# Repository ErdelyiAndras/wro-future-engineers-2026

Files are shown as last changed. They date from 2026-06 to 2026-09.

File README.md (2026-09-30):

# WRO Future Engineers 2026

## Introduction

We're team Bits from Hungary, competing in the WRO Future Engineers category. This engineering documentation covers all major aspects of the robot's development: mobility management, power and sensor systems, obstacle detection, avoidance and construction design.

### Team members:

 - András Erdélyi
 - Balázs Erdélyi

### Coach:

 - Norbert Boros

## Abstract

Our solution is an autonomous robot built around a Raspberry Pi 5 programmed in Python and C++, responsible for the main challenge logic and vision processing, and an Arduino Nano, responsible for low-level tasks such as motor and servo control. We use a 360° RPLIDAR A2M8 combined with the gyroscope of a BNO055 IMU to track the robot's position and heading. Traffic signs are detected with a USB camera. Steering uses a HS-485HB servo with positive Ackermann geometry. Driving is powered by one N20E-12-500 DC motor and a DRV8871 H-bridge, through a rear-axle differential with a custom 3D-printed housing. The compact dual-plate chassis is powered by a custom 3S 18650 battery pack with a BMS and buck converters.

## Table of Contents

- ### Videos

    - [**Open Challenge**](https://www.youtube.com/watch?v=D1SUvafeCVA)
    - [**Obstacle Challenge**](https://youtu.be/72qxD-1WuEM)

- ### Hardware
    -  [**Assembly Overview**](docs/hardware/assembly-overview.md)
    -  [**Drive System**](docs/hardware/drive-system.md)
    -  [**Processing Units**](docs/hardware/processing-units.md)
    -  [**Sensors**](docs/hardware/sensors.md)
    -  [**Power and Electronics**](docs/hardware/power-and-electronics.md)
    -  [**Circuit Design**](docs/hardware/circuit-design.md)
    -  [**Cost of the Robot**](docs/hardware/cost-of-the-robot.md)
    -  [**3D Print**](docs/hardware/3d-print.md)
    -  [**Assembly Guide**](docs/hardware/assembly-guide.md)

- ### Software
    -  [**Architecture Overview**](docs/software/architecture.md)
    -  [**Components**](src/rpi/components/README.md)
    -  [**Control / Blackboard**](src/rpi/control/README.md)
    -  [**Processors & Planning Algorithm**](src/rpi/processors/README.md)
    -  [**Recording & Replay**](src/rpi/recording/README.md)
    -  [**Visualizers**](src/rpi/visu/README.md)
    -  [**Arduino Firmware**](src/arduino/README.md)
    -  [**Calibration**](calibration/README.md)
    -  [**Previous Approaches**](docs/software/previous-approaches.md)
    -  [**Developer & Setup Guide**](docs/software/setup-guide.md)

## Special Thanks

We'd like to thank Széchenyi István University, Facenter Kft., and Filasin for supplying us all the equipment that made our preparation possible.

<table>
<tr>
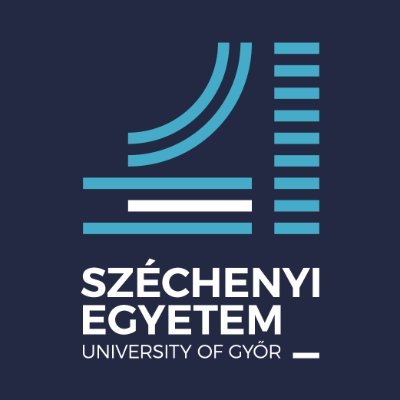
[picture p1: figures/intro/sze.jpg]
<td valign="top" width="240"></td>
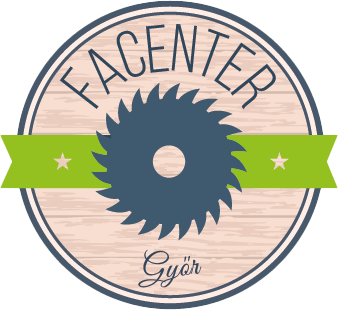
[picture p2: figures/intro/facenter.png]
<td valign="top" width="240"></td>
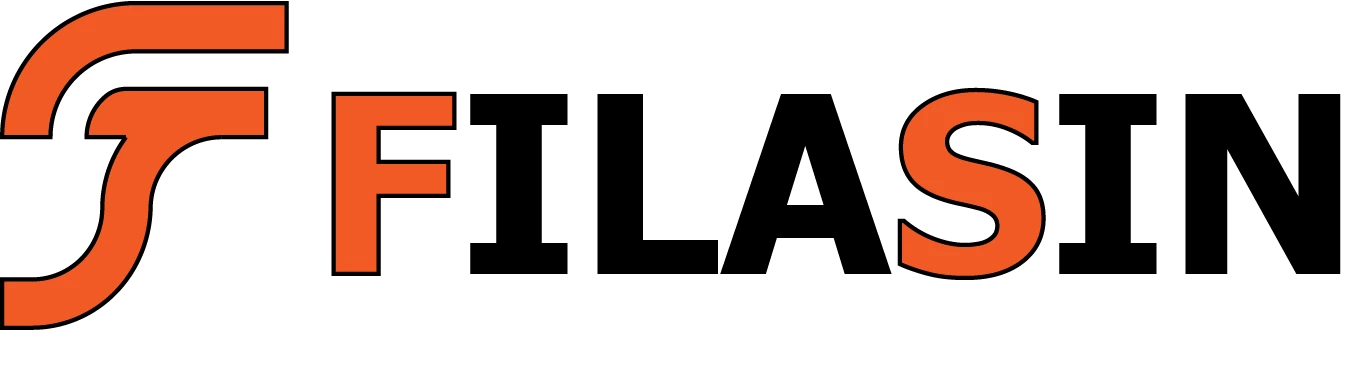
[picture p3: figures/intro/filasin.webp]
<td valign="center" width="240"></td>
</tr>
</table>

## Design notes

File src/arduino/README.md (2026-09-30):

# Arduino firmware

The Arduino Nano runs the **real-time motion layer**. It owns the BNO055 IMU and the wheel
encoder, receives body-frame targets from the Raspberry Pi over a framed serial link, and
drives the motor and steering to reach them — all in a tight loop (≥ 50 Hz). The Pi decides
*where* to go; this firmware decides *how* to get there. See the
[architecture overview](../../docs/software/architecture.md) for the split.

Build and flash with the repo `Makefile` (`make flash`, FQBN
`arduino:avr:nano:cpu=atmega328`); see the
[developer guide](../../docs/software/setup-guide.md#flashing-the-arduino).

## Main loop — [`arduino.ino`](arduino.ino)

`setup()` initialises the encoder, IMU, motor, steering, and protocol callbacks. `loop()`
runs every iteration:

```
encoder.update();      // refresh speed
imuCtrl.update();      // refresh heading
protocol.update();     // parse any incoming frames -> onSetTarget / onStop
navigator.update();    // pursue the current target
motor.update();        // apply the motor command (with kickstart)
// every 20 ms: protocol.sendState(heading, speed, steering, delta_distance)
```

So the Pi receives a `STATE` frame at **50 Hz** (`STATE_REPORT_INTERVAL_MS = 20`). The
modules are cooperating singletons (`navigator`, `motor`, `encoder`, …) configured entirely
from [`Config.h`](Config.h).

## `Protocol` — framed UART — [`Protocol.cpp`](Protocol.cpp)

The binary framing layer. Frame format:

```
[0xAA] [MSG_ID] [LEN] [PAYLOAD × LEN] [CRC8]
```

CRC-8 (polynomial `0x07`) is computed over `MSG_ID + LEN + PAYLOAD`; on a bad start byte or
CRC the parser drops one byte and resyncs. Messages:

| ID | Dir | Name | Payload |
|---|---|---|---|
| `0x01` | Pi → Nano | `SET_TARGET` | `forward_mm, lateral_mm, speed` (3× f32) |
| `0x02` | Nano → Pi | `STATE` | `heading_rad, speed, steering_rad, distance_mm` (4× f32) |
| `0x03` | Pi → Nano | `STOP` | empty |

`STATE.distance_mm` is the encoder distance **since the last report** (the Pi's EKF predict
step). The Python half of this protocol is [`components/Arduino.py`](../rpi/components/README.md).

## `Navigator` — pursuit + heading PID — [`Navigator.cpp`](Navigator.cpp)

The motion controller. `setTarget(forward, lateral, speed)`:

- **rejects unreachable targets** — a point inside either minimum-turn-radius circle
  (`r = wheelbase / tan(MAX_STEER)`) can't be reached with Ackermann steering, so the state
  goes `IDLE`. (This is why the planner runs every target through `_make_reachable`.)
- resets its local body frame (`x = y = 0`, heading reference = current IMU heading) and
  starts `PURSUING`. A **negative speed means reverse** (the steering sign is flipped).

`doPursuing()` each tick: integrate encoder distance into the local `(x, y)` using the IMU
heading; compute the heading error to the target (switching to a **heading-hold** mode within
100 mm to avoid oscillation); run a **PID** on that error (filtered derivative, clamped
integral) to a clamped steering angle; and set a speed with an **acceleration ramp** over the
first 200 mm and a **deceleration ramp** over the last 500 mm. Arrival (within 10 mm) brakes
and idles.

Key constants (`Config.h`): `HEADING_KP/KI/KD = −2.5 / −0.7 / −0.155`,
`HEADING_HOLD_RADIUS = 100 mm`, `ARRIVAL = 10 mm`, `MIN_SPEED = 80`, `MAX_STEER = 0.4014 rad`.

> **No serial watchdog.** The firmware does not auto-stop if the Pi goes silent; a `STOP`
> frame (or the start button on the Pi) ends a run. Worth adding before competition.

## `Motor` — [`Motor.cpp`](Motor.cpp)

Drives the DC motor via two PWM channels (forward `D5`, reverse `D6`). Implements a
**kickstart**: starting from rest below the deadband, it briefly applies `MIN_SPEED` (80)
and decays toward the requested speed at `KICKSTART_DECAY = 200` units/s, overcoming static
friction without a jerk. `brake()` drives both channels high (active brake); `stop()` coasts.
`MOTOR_DIR = −1` accounts for the wiring polarity.

## `Steering` — [`Steering.cpp`](Steering.cpp)

Maps a steering angle (rad) to a servo pulse width, with **asymmetric** left/right ranges
because the servo's mechanical centre is off the electrical centre: centre `1050 µs`, full
left `1400 µs`, full right `500 µs`, max `±0.4014 rad`. These values live in
[`Config.h`](Config.h), measured from the servo pulse-width → wheel-angle mapping.

## `Encoder` — [`Encoder.cpp`](Encoder.cpp)

Quadrature decoding on interrupt pins `D2` / `D3`; `TICKS_PER_MM = 14.0`. Speed is sampled
every 50 ms; `distance` reported to the Pi is the delta since the last `STATE`.

## `IMU` — [`IMU.cpp`](IMU.cpp)

The BNO055 over I²C in **`OPERATION_MODE_IMUPLUS`** — gyro + accelerometer fusion, **no
magnetometer** (a magnetometer is unreliable near motors and metal). Heading is therefore
**relative**: it is zeroed at boot, so `yaw = 0` points wherever the robot happened to face
at power-on. Recovering "parallel to the wall" from that arbitrary zero is exactly the job of
the principal angle `theta` on the Pi side (see the
[processors chapter](../rpi/processors/README.md)).

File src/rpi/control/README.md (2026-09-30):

# Control — the blackboard

`control/` holds the **shared state** of the Raspberry Pi software: the thread-safe
"blackboard" that sensor threads write and the planner reads, plus the small value types the
colour pipeline uses. It holds **no maps or grids** — only the scalars the reactive stack
reasons about. See the [architecture overview](../../../docs/software/architecture.md) for
the blackboard pattern.

Each accessor takes a lock for only as long as it takes to read or write a few numbers, so
threads running at different rates never block each other.

## `EgoInformation` — [`EgoInformation.py`](EgoInformation.py)

The robot's pose estimate `[x, y, heading]`, maintained by a small **Extended Kalman
Filter**. It is updated by [`ArduinoProcessor`](../processors/README.md) on every `STATE`
frame (50 Hz):

- **Predict** — `update_odometry(ds, steering)` propagates the state with Ackermann
  kinematics (straight-line when steering ≈ 0, arc otherwise) and advances the covariance
  `P` through the analytic Jacobian plus a process-noise term scaled by the distance
  travelled.
- **Correct** — `update_imu(heading)` folds the BNO055 heading in as a scalar measurement,
  correcting heading drift.

The planner consumes **`yaw`** (heading) and, for dead-reckoning lateral drift within a
straight, the **`position`** deltas. It does **not** use the absolute `(x, y)` as a world
position — there is no map to place it in. The noise constants (`_PROCESS_NOISE_V`,
`_PROCESS_NOISE_W`, `_MEAS_NOISE_IMU_HDG`) are measured empirically on the assembled robot.

> Historical note: the EKF also has a LiDAR `[x, y, heading]` correction path in earlier
> revisions; the current reactive pipeline does not wire one in. See
> [Previous approaches](../../../docs/software/previous-approaches.md).

## `TrackModel` — [`TrackModel.py`](TrackModel.py)

The track as the robot currently understands it — a lock-protected bag of scalars written by
two processors and read by the planner:

| Field | Meaning | Written by |
|---|---|---|
| `theta` | principal angle: grid orientation, mod 90°, absolute (gyro) frame | `PrincipalAngleDetector` |
| `theta_seeded`, `theta_from_gyro`, `theta_frozen` | seed status / detection freeze | detector + planner |
| `seg_k` | grid multiple of the **current** straight; latched per straight, bumped by `turn_sign` at each corner | planner |
| `turn_sign` | `+1` CW / `−1` CCW, latched at the first corner | planner |
| `corner_count` | corners completed (12 = 3 laps) | planner |
| `current_lane`, `target_offset` | the lane held vs the lane aimed at | planner |
| `target_heading` | corner target heading | planner |

The one derived quantity, `segment_heading(yaw) = wrap(theta + seg_k·90°)`, lives here
because both its inputs do. Latching `seg_k` per straight (rather than re-deriving it from
the live yaw each scan) is what makes the mid-straight 90° "grid flip" structurally
impossible — a story told in [Previous approaches](../../../docs/software/previous-approaches.md).

## Colour types

- [`ColorRange.py`](ColorRange.py) — an HSV colour as the **union of one or more
  `(lower, upper)` bands**, so a hue that straddles the 0/180 seam (red, or the magenta
  parking wall) is two bands instead of being clipped. `mask()` / `ratio()` test a patch
  against it. The three ranges (red, green, parking) are produced by the
  [obstacle-colour calibration](../../../calibration/README.md#obstacle-colours) and pasted
  into `main_obstacle.py`.
- [`ObstacleColor.py`](ObstacleColor.py) — the `RED` / `GREEN` enum the pillar reader
  returns.

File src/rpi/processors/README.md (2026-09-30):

# Processors & the planning algorithm

Processors are the algorithms. Each subscribes to a component [`Event`](../utils/Event.py),
and inherits from [`Processor`](Processor.py) — a thin base whose `__call__` forwards to
`_process(...)` (and can be paused). This chapter covers the perception processors and then
the heart of the robot: the **reactive segment planner** and its state machine.

For how these wire into the rest of the system, see the
[architecture overview](../../../docs/software/architecture.md). For the ideas we tried
first (occupancy grid, SLAM, follow-the-gap), see
[Previous approaches](../../../docs/software/previous-approaches.md).

## Perception processors

- **[`ArduinoProcessor`](ArduinoProcessor.py)** — subscribes to `Arduino.on_state`. On each
  `STATE` frame it feeds `EgoInformation`: an odometry predict step (if the robot moved ≥
  0.5 mm) and an IMU heading correction. This is the only writer of the EKF pose.
- **[`CameraProcessor`](CameraProcessor.py)** — the **stateless, body-frame pillar-colour
  reader**. It keeps the latest camera frame and, on demand, answers
  `color_at(forward, lateral)`: project a body-frame point into the image through the camera
  intrinsics/extrinsics, sample a 20 px HSV patch, and classify it against the red/green
  [`ColorRange`s](../control/README.md). Because the extrinsics are body-relative, **no ego
  pose is involved** — the planner clusters a pillar in the *current* scan and hands its
  body point straight over. `parking_wall_ratio()` (whole-frame magenta) is used once at a
  parking-slot start. It also defines `CameraIntrinsics` / `CameraExtrinsics`.
- **[`PrincipalAngleDetector`](PrincipalAngleDetector.py)** — fits the track's principal
  angle `theta` each scan and publishes it to [`TrackModel`](../control/README.md); detailed
  below.

## The core idea

The planner is **deterministic, reactive, and sensor-only**. It *assumes* the WRO layout — a
rectangular loop of four straights joined by four 90° corners — and trades that assumption
for determinism. It keeps no occupancy grid, no world position, and no obstacle map. Two
principles carry the whole thing:

1. **Open-loop straights, closed-loop corners.** A straight is driven with **no lateral wall
   term**: the firmware holds heading toward an aim point placed down the segment, and
   lateral position is dead-reckoned from encoder + gyro. Every corner ends with a
   closed-loop **reset** (align to the new segment against the LiDAR rear wall). So lateral
   error can build up over at most *one* straight and is wiped at each corner — it never
   compounds across the three laps. This is also why the receding inner wall near a corner
   never corrupts anything: the straight simply does not look at the side walls.

2. **Gyro holds heading; LiDAR calibrates what "parallel" means.** The IMU zero is an
   arbitrary placement angle, so `yaw = 0` is not "parallel to the wall". The principal
   angle `theta` (grid orientation, mod 90°) is fit from the wall points; the current
   `segment_heading = theta + seg_k·90°` is what the straight is driven along. `theta` is
   yaw-invariant, so it stays valid through lane switches and corners.

Each scan the planner outputs just a body-frame aim point + speed; the firmware's
`Navigator` turns that into steering and motor commands (see the
[firmware chapter](../../arduino/README.md)).

## Principal angle `theta`

`PrincipalAngleDetector` estimates the grid orientation from **wall tangents**: between two
consecutive LiDAR returns on the same surface, the segment direction is a wall tangent. Both
corridor side walls and the perpendicular end wall lie on the same 90° grid, so every clean
tangent reinforces the same mod-90 angle. Tangents are accumulated as unit vectors on
`4·angle` (which handles the mod-90 wrap), length-weighted; the resultant length doubles as
a **fit-quality gate** — messy, mid-turn scans (low resultant) are skipped, clean straights
absorbed into a circular-mean EMA. The body-frame result is lifted into the absolute frame
with the gyro yaw, which is what makes `theta` yaw-invariant.

Because a corner start cannot produce a clean fit, if no LiDAR fit lands within
`_SEED_FALLBACK_SCANS` (12) scans the detector **seeds `theta` from the gyro** so the robot
can start moving; the EMA then refines it once a straight is in view. The detector is wired
**before** the planner on the LiDAR thread, so the planner reads a fresh `theta` the same
scan.

## The state machine

One LiDAR scan is one tick of the machine. `ObstacleChallengePlanner` implements the full
version below; `OpenChallengePlanner` is the same minus `LANE_SWITCH` and the parking states.

Planner state machine

| State | What it does |
|---|---|
| `INIT` | wait until `theta` seeds, then branch: normal start → `DRIVE_STRAIGHT`; `--parking-start` → `PARK_LEAVE` (after voting the exit side) |
| `DRIVE_STRAIGHT` | hold `segment_heading`; split the forward cone into end wall vs pillar; apply the sticky lane; arm a corner when the end wall crosses the trigger |
| `LANE_SWITCH` | drive to a point beside the pillar in the mandated lane (corner trigger disabled so the switch always finishes) |
| `CORNER` | play a scripted, arrival-lane-specific recipe (below) |
| `PARK_LEAVE` | 3-step maneuver out of the parking slot: K-turn → approach inner wall → reverse-out to the segment |
| `PARK_SETTLE` | dwell, reading the first pillar's colour on motion-free frames before driving |
| `PARK` | final parking at the end of the run (`--park-mode perpendicular`) |
| `DONE` | stopped (`on_stop()` fired) |

### Straights and the sticky lane

There are three lanes: left / centre / right = corridor centre ± `_LANE_OFFSET` (300 mm). A
lane is **held** even when off-centre; it changes only when a pillar mandates it (WRO rule:
red → pass on its right, green → on its left). The forward cone is re-aimed away from the
near wall in proportion to the current lane, so a wall the robot is hugging is not misread as
a pillar. The end-wall distance is a high percentile of the cone (ignoring a nearer pillar);
a compact cluster well in front of the end wall is the pillar.

### Obstacle colour: read once, remember

A pillar's colour is resolved by a short **majority vote** over camera reads (so one bad
frame can't flip the lane), then **stored** keyed by `(segment, distance-from-end-wall)`. On
later laps a re-detected pillar within tolerance **recalls** the stored colour, so the lane
is correct even if the camera misreads that pass. On the start straight a "free-standing"
test rejects the magenta parking wall (continuous with the perimeter) so it is never treated
as a pillar.

### Corners: three recipes by arrival lane

`turn_sign` (CW/CCW) is latched once, at the first corner, from the LiDAR opening — deferred
until one side is genuinely open so a lane-hugging robot can't pick the wrong way early. The
arrival lane then selects the recipe, each ending in the **same** closed-loop rear-wall
align/standoff step:

| Arrival lane | Recipe |
|---|---|
| **outer** (opposite the turn) | forward quarter-turn → rear-wall align |
| **centre / inner** (turn side) | reverse-arc turn (rotate while backing) → rear-wall align |

Each arc is gyro-terminated a **lead angle** before the target so the robot's coast lands it
on target (the firmware never decelerates the arc under per-scan re-emit); the rear-wall step
then closes the loop on both heading and standoff. Every reverse target is passed through
`_make_reachable`, which snaps an in-circle target onto the minimum-turn-radius circle so the
firmware cannot silently reject it.

### Lane switches

A switch drives to a point **beside the pillar** — forward = the pillar's longitudinal
distance (latched, then coasted on odometry once it leaves the cone), lateral = the mandated
lane. The bearing is capped well short of 45°; a sharper target is pushed farther ahead
instead of aimed sideways, preserving forward progress. It completes only when the lane is
actually reached.

### Parking

`main_obstacle.py` supports a parking-slot **start** (`--parking-start`, plays the
`PARK_LEAVE` maneuver) and a final **park** (`--park-mode perpendicular`: K-turn to face the
outer wall, then drive in between the two parking walls and stop when flanked, with a hard
wall-clock timeout so a stall can never loop). The parallel-parking variants are stubs.

## `OpenChallengePlanner` — [`OpenChallengePlanner.py`](OpenChallengePlanner.py)

The open challenge has no pillars, no parking, and no lane choices, so this is a deliberately
stripped sibling: follow the segment's principal angle, and do the **outer** forward-turn
corner at every wall. The corner constants are copied verbatim from the obstacle planner, so
the tuning matches. It is a standalone duplicate rather than a subclass (the shared
primitives could be factored into a base later), and it emits the identical
`on_target` / `on_stop` / `on_debug` contract, so the recorder and visualizers work unchanged.

## Tuning surface

Nearly every threshold is a named class constant at the top of
[`ObstacleChallengePlanner.py`](ObstacleChallengePlanner.py) with a comment explaining it.
The corners are not symmetric (left vs right servo/steer trim differs), so the front triggers
and parking standoffs are **split by track direction** (`_CW` / `_CCW`) — tune each side on
its own.

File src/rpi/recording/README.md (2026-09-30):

# Recording & replay

The `Recorder` writes **every frame of every subscribed signal** into one HDF5 file per run,
so a run can be replayed and inspected offline. It is how we debug the planner: almost every
fix in [Previous approaches](../../../docs/software/previous-approaches.md) was root-caused
from a `.h5` file. Recording is on by default; pass `--no-record` to disable it. Files land
in `recordings/run_<timestamp>.h5`.

## How it works — [`Recorder.py`](Recorder.py)

The `Recorder` taps [`Event`s](../utils/Event.py) exactly like any other subscriber. The
producer-side handler only timestamps, cheaply packs the payload, and enqueues it; a **single
writer thread** owns the h5py file (h5py is not thread-safe). If the queue is full the frame
is **dropped and counted** — a sensor thread is never blocked by disk I/O. The file is opened
in **SWMR** mode and flushed every second, so it stays readable after a crash or power cut,
losing at most ~1 s of data.

All `attach_*` calls happen in the main **before** the run starts (SWMR forbids creating
datasets later). Each maps a payload kind to a stream:

| `attach_*` | Stream kind | Used for |
|---|---|---|
| `attach_scan` | `scan` | LiDAR scans + the ego pose sampled at that instant |
| `attach_array` | `array` | fixed-width rows — the `STATE` frame, the ego pose, planner targets |
| `attach_marker` | `marker` | timestamp-only events (e.g. `on_stop`) |
| `attach_npz` | `npz` | variable dicts — the planner's per-scan `on_debug` payload |
| `attach_jpeg` | `jpeg` | encoded camera frames |
| `attach_planner` | — | convenience: wires up a planner's `on_target` / `on_stop` / `on_debug` / `on_track_heading` in one call |

Every file also stores metadata: schema version, wall/monotonic `t0`, the launching script,
the planner class, the **git commit**, and any notes — so a recording is self-describing.

## Reading a run — [`Recording.py`](Recording.py)

`Recording` is the read side. `iter_stream(name)` yields `(t, payload)` per frame;
`iter_merged(...)` interleaves several streams in monotonic-time order — the entry point for
replaying a run against a planner. It transparently handles a file left "open for write" by a
crashed run by reopening it as an SWMR reader, and truncates to the shortest dataset so a
half-flushed file still reads.

## The CLI — `python -m recording`

Run from `src/rpi/` (so the package imports resolve):

```bash
python -m recording summary <run.h5>              # per-stream counts, rates, sizes, drops
python -m recording scans   <run.h5> [--worst N]  # per-scan LiDAR dropout stats
python -m recording dump     <run.h5> <stream>    # decode and print a stream's events
```

`python -m recording <run.h5>` with no subcommand defaults to `summary`. See the
[developer guide](../../../docs/software/setup-guide.md) for the full recording/replay
workflow.

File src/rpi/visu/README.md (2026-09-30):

# Visualizers — live debug views

Three lightweight web visualizers stream the robot's live state to a browser, so we can
watch what the planner sees during a run (on the robot or over the
[private network](../../../docs/software/setup-guide.md#remote-access-with-tailscale)). Each
runs its own threaded HTTP server and, like everything else, is just an
[`Event`](../utils/Event.py) subscriber — the hot path does not know they exist. They are
started with `--visu` on either main.

The package is kept **import-light on purpose**: import the specific module you need so a
consumer that only wants the LiDAR view does not pull in the OpenCV/camera stack.

| Visualizer | Port | Subscribes to | Shows |
|---|---|---|---|
| [`LidarVisualizer`](LidarVisualizer.py) | **8082** | `lidar.on_scan` | the raw scan as a polar scatter, robot at centre, coloured by return quality |
| [`PathPlanningVisualizer`](PathPlanningVisualizer.py) | **8084** | `planner.on_debug` | the planner's full per-scan state (below) |
| [`ColorVisualizer`](ColorVisualizer.py) | **8085** | `camera.on_frame` | the live frame with the last `color_at` query overlaid |

Open `http://<robot-host>:<port>` in any browser on the same network. With `--visu` (and
without `--no-browser`) the mains open them automatically.

## `PathPlanningVisualizer` (the main one)

Renders the planner's per-scan debug payload as a polar plot, robot at centre, forward up.
It is the single most useful view for this planner — it shows, in one picture:

- the raw scan (grey) and the returns inside the **forward cone** (cyan wedge, re-aimed by
  the current lane) — the wall/obstacle split window;
- the **segment direction** the gyro is holding (yellow ray) and the measured **end-wall
  distance** against the `FRONT_TRIGGER` arc (red);
- the detected **obstacle**, coloured by the camera read (red / green / grey = unresolved);
- the three **lanes** and the dead-reckoned **lateral position** in the corridor;
- during `LANE_SWITCH`, the **target point** sent to the firmware (purple cross);
- the commanded **aim point** (orange), and the rear-wall standoff during a corner;
- a text block: state, grid angles, distances, lane, corner count, speed.

## `ColorVisualizer`

The direct check on the colour half of the obstacle pipeline: the live frame with the most
recent `CameraProcessor.color_at` query drawn on it — where the LiDAR obstacle projected into
the image, the HSV sample patch, the red/green coverage ratios, and the verdict. If the
projected point does not land on the pillar, the camera **extrinsics** need re-measuring
(see [calibration](../../../calibration/README.md)). The overlay fades to grey when no
obstacle has been queried recently.

Because the same `on_debug` stream is archived by the [`Recorder`](../recording/README.md),
anything the planner visualizer shows live can also be reconstructed from a `.h5` after the
run.

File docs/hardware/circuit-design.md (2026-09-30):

# Circuit Design

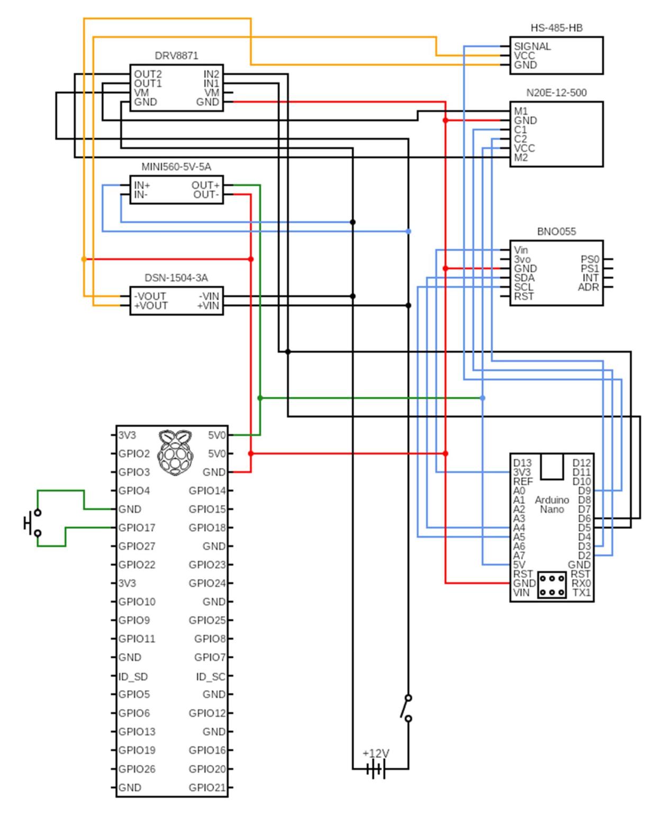
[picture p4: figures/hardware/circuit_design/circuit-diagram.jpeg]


The camera, the Arduino, and the LiDAR are connected to the Raspberry Pi via USB.

To make repairing and debugging easier, we used color-coded wires.

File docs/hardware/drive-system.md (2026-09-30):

# Drive System

### DC Motor: N20E-12-500

<table>
<tr>
<td valign="top">

| Specs | Value |
|---|---|
| Voltage | 12 V |
| Speed | 500 RPM |
| Torque | 41 mNm |
| Current | 100 mA |
| Dimensions | 26 × 10 × 12 mm |
| Shaft | 3 mm diameter, D-spring contact interface |

</td>
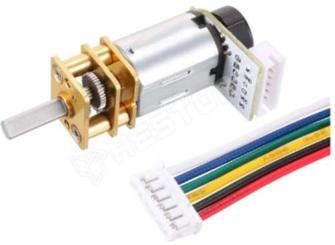
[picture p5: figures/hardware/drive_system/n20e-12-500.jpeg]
<td valign="top" width="240"></td>
</tr>
</table>

Due to its compact size and adequate torque, the N20E motor was selected to drive the robot; it features a built-in encoder to provide precise feedback. The motor connects via a 3D-printed axle to the LEGO gears and subsequently to the LEGO differential. The motor is mounted to the differential housing using a LEGO-style bracket, and the housing itself is secured to the baseplate with screws.

**Previous tries:** We tried another version of this motor, the N20E-12-1000, but it couldn't provide sufficient torque to move the robot consistently.

**Mounting:**
- 3 pcs M3×3×4.2 mm inserts
- 3 pcs M3×8 mm screws

### Motor Controller: DRV8871-MK

<table>
<tr>
<td valign="top">

| Specs | Value |
|---|---|
| Voltage | 6.5 – 45 V |
| Max. current | 3.6 A |
| Dimensions | 25 × 21 × 9.5 mm |

</td>
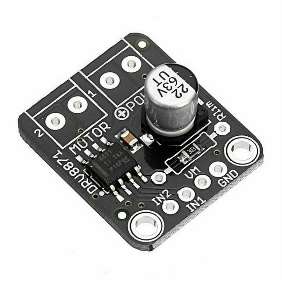
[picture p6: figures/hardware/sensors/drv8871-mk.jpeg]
<td valign="top" width="240"></td>
</tr>
</table>

The DRV8871-MK is a DC motor driver used to control the speed, direction, and braking of the DC motor.

**Previous ideas:** We tried the L298N motor driver, however it was proven to be overkill for our project. That controller can manage 2 DC motors at the same time and it's also huge in size compared to the DRV8871 and our robot's size.

**Mounting:**
- 2 pcs M2×10 mm screws
- 2 pcs M2 nuts

### Servo: HS-485HB

<table>
<tr>
<td valign="top">

| Specs | Value |
|---|---|
| Voltage | 4.8 – 6 V |
| Speed (60°) | 0.22 – 0.18 s |
| Torque range | 4.8 – 6 kg·cm |
| Current draw (idle) | 10 mA |
| Stall current draw | 1200 mA |
| Dimensions | 39.8 × 19.8 × 38.0 mm |
| Weight | 45 g |

</td>
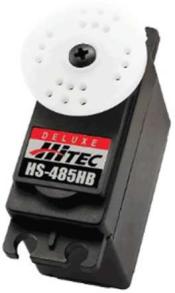
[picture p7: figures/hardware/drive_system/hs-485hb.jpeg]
<td valign="top" width="240"></td>
</tr>
</table>

The HS-485HB is a small servo motor that has enough torque to move our steering mechanism and is small enough to fit on the front of the robot.

**Mounting:**
- Servo mount: 2 pcs M4×5×5 mm inserts, 2 pcs M4×8 mm screws
- Servo motor: 2 pcs M4×6×5 mm inserts, 2 pcs M4×6 mm screws

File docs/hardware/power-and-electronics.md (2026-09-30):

# Power and Electronics

### Power Source: EVE INR18650 + BMS 3S 20A

<table>
<tr>
<td valign="top">

| Battery Specs | Value |
|---|---|
| Capacity | 3500 mAh |
| Current | 10 A |
| Voltage | 4.2 V |
| Nominal voltage | 3.7 V |
| Dimensions | 59 × 20 × 3.7 mm |
| Max. pulse current | 20 A |

</td>
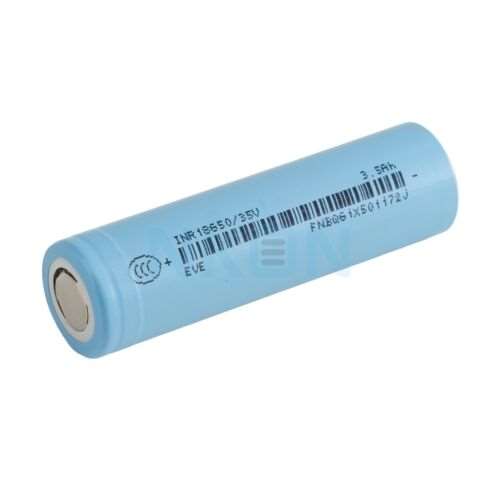
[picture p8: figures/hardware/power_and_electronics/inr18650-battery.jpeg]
<td valign="top" width="240"></td>
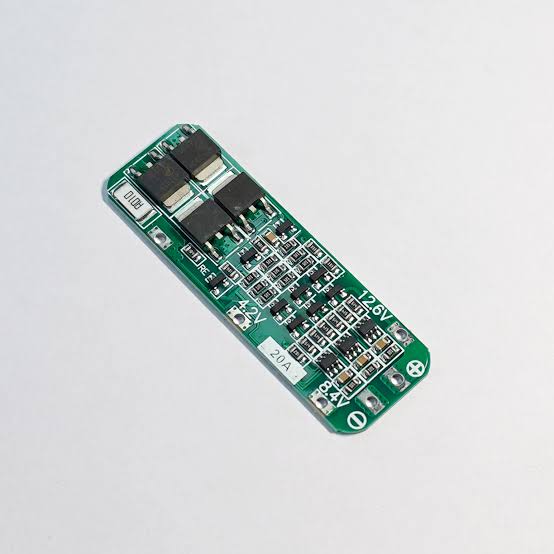
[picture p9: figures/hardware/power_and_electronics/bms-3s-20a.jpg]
<td valign="top" width="240"></td>
</tr>
</table>

**BMS specs:** Protection against overcurrent, over-discharge, overcharge, and short circuit. Operating current: 10 A.

The robot's power supply is provided by a custom-built, series-connected (3S1P) battery pack consisting of three 18650 cells. A BMS is integrated into the system to ensure stable output voltage and current, while protecting the cells and the circuit against overcurrent, over-discharge, overcharge, and short circuits. The Raspberry Pi 5 requires 5V and 5A to operate, its power supply is managed by an MINI560-5V-5A step-down converter. The camera, LiDAR, and Arduino receive their power directly from the Raspberry Pi via USB ports. The servomotor is powered by a separate DSN-1504 converter, with its output set to approximately 5V. The other electronic components receive power from the Arduino's pins.

**Mounting:**
- 4 pcs M3×5×4.2 mm inserts
- 4 pcs M3×8 screws
- 4 pcs M3×4×4.2 mm inserts
- 4 pcs M3×6 screws

### Stepdown: MINI560-5V-5A

<table>
<tr>
<td valign="top">

| Specs | Value |
|---|---|
| Input voltage | 4 – 36 V |
| Output voltage | 5 V |
| Current | 5 A |
| Dimensions | 29 × 18 × 5.4 mm |

</td>
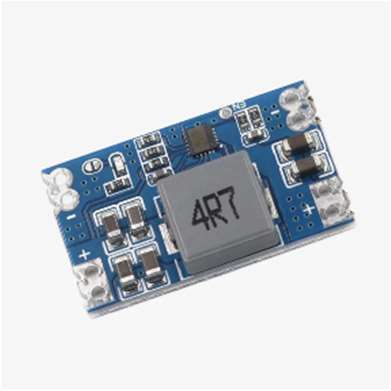
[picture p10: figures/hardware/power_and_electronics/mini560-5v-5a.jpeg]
<td valign="top" width="240"></td>
</tr>
</table>

This stepdown is used for the Raspberry Pi 5 to supply 5 V and 5 A for it.

**Previous tries:** The XL4015-STDN-PSU DC-DC converter was unable to supply sufficient current to meet the demands of the Raspberry Pi. This power deficit resulted in voltage drops, triggering unstable behavior and intermittent, random system shutdowns.

**Mounting:**
- 2 pcs M3×5×4.2 mm inserts
- 2 pcs M3×8 mm screws
- 2 pcs M2.5×4×3.5 mm inserts
- 2 pcs M2.5×10 mm screws

### Stepdown: DSN-1504-3A

<table>
<tr>
<td valign="top">

| Specs | Value |
|---|---|
| Input voltage | 4.5 – 20 V |
| Output voltage | 0.8 – 18 V |
| Current | 3 A |
| Dimensions | 22 × 17 × 4 mm |

</td>
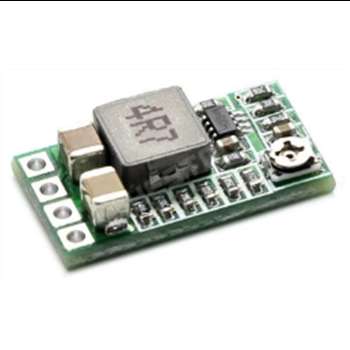
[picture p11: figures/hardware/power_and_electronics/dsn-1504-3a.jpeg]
<td valign="top" width="240"></td>
</tr>
</table>

This stepdown is used for the servo motor to supply sufficient power for it.

**Mounting:**
- 2 pcs M3×3×4.2 mm inserts
- 2 pcs M3×6 mm screws

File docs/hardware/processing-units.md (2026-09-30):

# Processing Units

### Raspberry Pi 5 (8 GB)

<table>
<tr>
<td valign="top">

| Specs | Value |
|---|---|
| Voltage | 5 V |
| RAM | 8 GB |
| Processor | ARM Cortex-A76 |
| Ports (used) | 2× USB 3.0, 1× USB 2.0 |
| Dimensions | 85 × 56 × 17 mm |

</td>
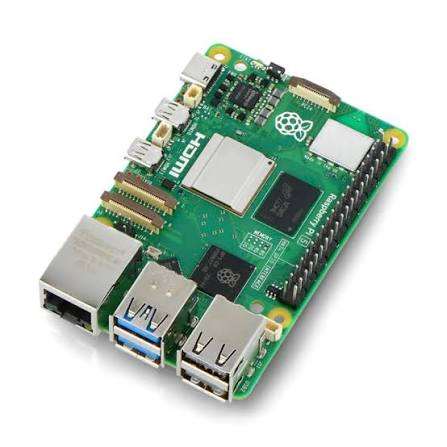
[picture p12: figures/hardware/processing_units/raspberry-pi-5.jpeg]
<td valign="top" width="240"></td>
</tr>
</table>

The Raspberry Pi 5 serves as our main computational unit. It processes real-time LIDAR and camera data and manages tasks like mapping and path planning.

**Mounting:**
- 4 pcs M2.5×8 mm screws
- 4 pcs M2.5×5×3.5 mm inserts

### Arduino Nano: AR-NANOCH-UNS-TYPE-C

<table>
<tr>
<td valign="top">

| Specs | Value |
|---|---|
| Microcontroller | Atmel Atmega32 |
| Voltage | 5 V |
| Dimensions | 45 × 18 mm |

</td>
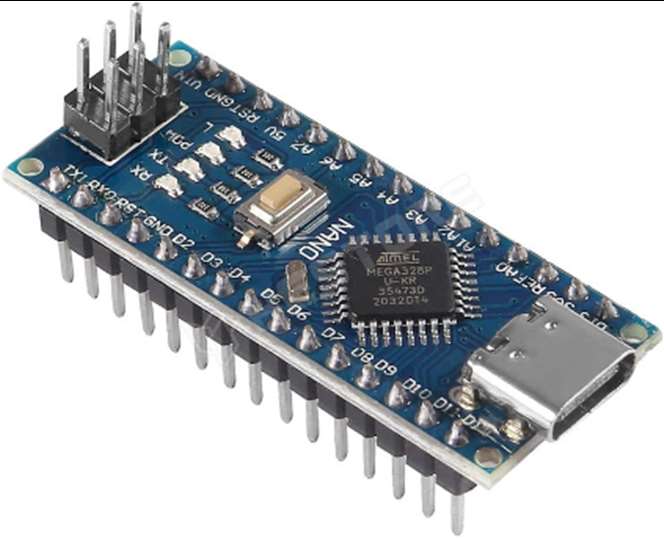
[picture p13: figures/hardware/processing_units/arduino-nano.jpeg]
<td valign="top" width="240"></td>
</tr>
</table>

The Arduino Nano serves as our secondary controller managing tasks such as motor control, servo steering and sensor inputs. It communicates with the Raspberry Pi 5 to ensure maximum control.

**Mounting:**
- 2 pcs M3×3×4.2 mm inserts
- 2 pcs M3×6 mm screws

**Previous ideas:** Level shifter (LS-BIDI-4) → USB. Previously the Raspberry and the Arduino communicated via a level shifter inside the robot, however it required 10 cables in total to connect them. So to save space and make it easier to take apart the robot we switched to a USB cable.

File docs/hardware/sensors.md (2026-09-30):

# Sensors

### LiDAR: RPLIDAR A2M8

<table>
<tr>
<td valign="top">

| Specs | Value |
|---|---|
| Distance range | 0.15 – 12 m |
| Sampling frequency | 8 kHz |
| Scan rate | Adjustable from 5 to 15 Hz |
| Angular range | 360° |
| Angular resolution | 0.9° |
| Dimensions | 76 × 76 × 41 mm |
| Weight | 190 g (sensor core) |

</td>
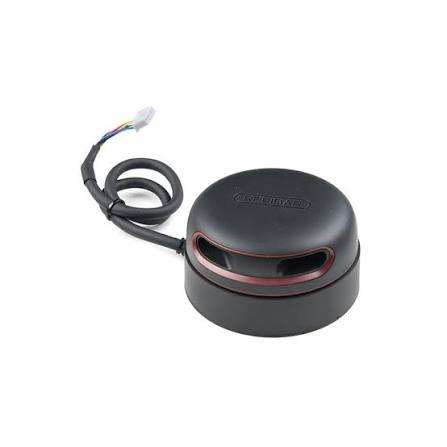
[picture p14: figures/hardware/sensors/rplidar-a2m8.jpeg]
<td valign="top" width="240"></td>
</tr>
</table>

This LIDAR allows us to make precise measurements of obstacles around the robot. The high sampling frequency allows real-time mapping and obstacle avoidance.

**Previous tries:** The RPLIDAR A3M1 LiDAR sensor did not provide sufficient point cloud density; consequently, precise navigation would not have been feasible due to the lack of detailed data.

**Mounting:**
- 4 pcs M3×8mm screws

### Camera: DFRobot FIT0701

<table>
<tr>
<td valign="top">

| Specs | Value |
|---|---|
| Voltage | 5V |
| Resolution | 640 × 480 px |
| Dimensions | 30 × 25 × 21.4 mm |

</td>
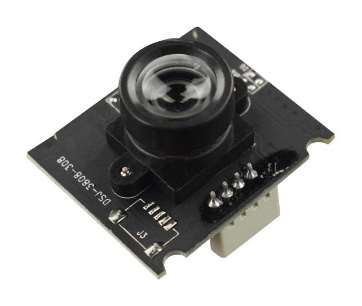
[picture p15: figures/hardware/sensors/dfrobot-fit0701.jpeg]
<td valign="top" width="240"></td>
</tr>
</table>

The camera is used for obstacle and color detection.

**Mounting:**
- 2 pcs M3×5×4.2 inserts
- 2 pcs M3×8 mm screws
- 2 pcs M2.5×5×3.5 mm inserts
- 2 pcs M2.5×8 mm screws

### IMU: BNO055

<table>
<tr>
<td valign="top">

| Specs | Value |
|---|---|
| Type | 9-axis IMU |
| Voltage | 3.3 V |
| Communication interface | I²C |

</td>
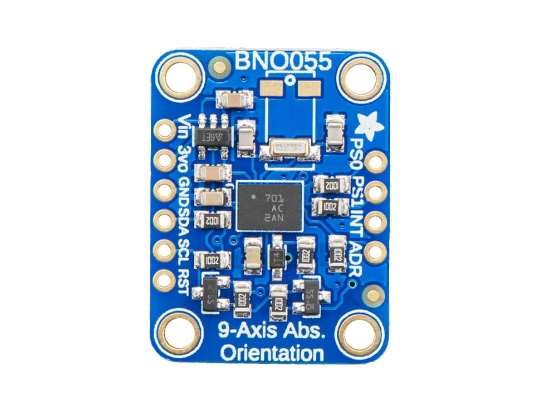
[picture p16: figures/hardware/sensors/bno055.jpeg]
<td valign="top" width="240"></td>
</tr>
</table>

The BNO055 provides real-time positional data, which helps the robot maintain correct direction and smooth out steering adjustments.

**Mounting:**
- 4 pcs M2×10 mm screw
- 4 pcs M2 nut

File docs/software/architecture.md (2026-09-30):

# Software Architecture

This is the high-level map of team Bits' software. It explains how the pieces fit
together; each subsystem then has its own chapter **next to the code it describes** (linked
below). For the algorithms we tried and dropped along the way, see
[Previous approaches](previous-approaches.md). To set up and run the robot, see the
[Developer & setup guide](setup-guide.md).

## Two processors, one clean boundary

The robot runs on two processors split by responsibility:

- **Raspberry Pi 5** — perception and decision making. Reads the LiDAR and camera, tracks
  the robot's heading and lane, decides where to go, and sends a motion target. Written in
  Python with background threads. *(C++ appears only in the firmware below.)*
- **Arduino Nano** — real-time motion execution. Owns the BNO055 IMU and the wheel encoder,
  and runs a tight control loop (≥ 50 Hz) that drives the motor and steering toward the
  target it was given.

The split exists because smooth motion control needs deterministic timing that a
general-purpose OS cannot guarantee, while perception and planning need CPU and libraries
the Arduino does not have. The Pi thinks; the Nano drives.

Package / component diagram

## The blackboard + event model (Raspberry Pi)

The Pi side is built from three kinds of object and one piece of glue:

| Kind | Role | Chapter |
|---|---|---|
| **Component** | hardware driver — runs a background thread, fires an `Event` on new data | [`src/rpi/components/`](../../src/rpi/components/README.md) |
| **Processor** | algorithm — subscribes to an `Event`, turns raw data into decisions/state | [`src/rpi/processors/`](../../src/rpi/processors/README.md) |
| **control** | the *blackboard* — thread-safe shared state everyone reads and writes | [`src/rpi/control/`](../../src/rpi/control/README.md) |
| **Event** | a tiny observer primitive (`+=` to subscribe, `handler(...)` to fire) | `src/rpi/utils/Event.py` |

**Event system.** Components never call processors directly. Each component exposes an
`Event` (`Lidar.on_scan`, `Camera.on_frame`, `Arduino.on_state`) and fires it when new data
arrives. Processors subscribe with `event += handler`. This decouples producers from
consumers and lets several consumers share one signal — the visualizers and the `Recorder`
simply subscribe to the *same* events as the planner, so nothing in the hot path knows they
exist. Handlers fire **synchronously, in subscription order, on the producer's thread**;
that ordering is load-bearing in one place (see below).

**Blackboard.** Shared state lives in `control/` — `EgoInformation` (the EKF pose/heading)
and `TrackModel` (principal angle, lane, corner count). Sensor threads write to it; the
planner reads from it. Every accessor takes a lock for only the microseconds it takes to
copy a few scalars — never during computation — so each thread runs at its own natural rate
without blocking the others.

Class diagram

## Thread & timing model

| Thread | Rate | Fires | Feeds |
|---|---|---|---|
| LiDAR | ~7 Hz (full rotations) | `Lidar.on_scan` | `PrincipalAngleDetector` → `TrackModel`, then the planner |
| Camera | up to 30 fps | `Camera.on_frame` | `CameraProcessor` (keeps the latest frame for on-demand colour reads) |
| Arduino serial reader | 50 Hz (STATE frames) | `Arduino.on_state` | `ArduinoProcessor` → `EgoInformation` |
| Recorder writer | drains a queue | — | one HDF5 file |

The planner is **driven by the LiDAR scan**, not a fixed clock: one scan is one decision.
On the LiDAR thread, `PrincipalAngleDetector` is subscribed **before** the planner, so it
refreshes the track's principal angle `theta` into `TrackModel` and the planner reads a
fresh value the same scan. That is the one place the synchronous, in-order event dispatch
matters.

## Data flow

Data flow — one control cycle

The Pi's job each scan boils down to choosing a **body-frame aim point** `(forward_mm,
lateral_mm)` and a `speed`. The firmware's `Navigator` does its own pure-pursuit and
heading-hold PID to reach it — so the Pi never computes a steering angle directly, and a
negative `speed` simply means *reverse*.

## Coordinate systems

- **Body frame** (the interface between Pi and Arduino): origin at the rear axle,
  **+forward** is the direction of travel, **+lateral is to the robot's right**. Both
  `set_target` and the camera projection use this frame.
- **Gyro heading `yaw`**: radians, wrapped to `(−π, π]`, zeroed at an *arbitrary* placement
  angle when the BNO055 boots — so `yaw = 0` is **not** assumed parallel to the track.
- **Principal angle `theta`**: the track's grid orientation, mod 90°, fit from the LiDAR
  walls. `segment_heading = theta + k·90°` is what the straight is driven along; this is how
  the planner recovers "parallel to the wall" from an arbitrary gyro zero. See the
  [processors chapter](../../src/rpi/processors/README.md).

> The robot keeps **no map and no world (x, y) position** for navigation. Everything is
> reactive: the current scan, the gyro heading, the wheel odometry, and a per-pillar camera
> colour read. This is a deliberate choice — see [Previous approaches](previous-approaches.md)
> for the occupancy-grid/SLAM stack it replaced.

## Two entry points

| Script | Challenge | Wiring |
|---|---|---|
| `src/rpi/main_open.py` | Open (no obstacles) | Lidar + Arduino + `PrincipalAngleDetector` + `OpenChallengePlanner` |
| `src/rpi/main_obstacle.py` | Obstacle (pillars, parking) | the above + Camera + `CameraProcessor` + `ObstacleChallengePlanner` |

Both share the same components, blackboard, recording, and visualizers; they differ only in
which planner is wired in. The general algorithm both run is a state machine over the four
straights and four corners of the loop — documented, with its diagram, in the
[processors chapter](../../src/rpi/processors/README.md).

## Chapter index

- [Components](../../src/rpi/components/README.md) — LiDAR, camera, and Arduino drivers
- [Control / blackboard](../../src/rpi/control/README.md) — `EgoInformation`, `TrackModel`, colour types
- [Processors & the planning algorithm](../../src/rpi/processors/README.md) — the state machine
- [Recording & replay](../../src/rpi/recording/README.md) — the HDF5 signal recorder
- [Visualizers](../../src/rpi/visu/README.md) — live LiDAR / planner / colour views
- [Arduino firmware](../../src/arduino/README.md) — Navigator, Motor, Steering, Encoder, IMU, Protocol
- [Calibration](../../calibration/README.md) — camera, colours, steering, odometry/IMU noise
- [Previous approaches](previous-approaches.md) — what we tried and dropped
- [Developer & setup guide](setup-guide.md) — flashing, running, SSH, recording

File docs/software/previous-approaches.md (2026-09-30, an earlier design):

# Previous approaches

The software that runs today — the deterministic, sensor-only
[reactive segment planner](../../src/rpi/processors/README.md) — is our **third** navigation
stack. This chapter records what came before and why we moved on, because the reasoning is as
much a part of the engineering as the final code. Each approach still lives in the git
history; the branch to check out is noted so the code and its commits can be read in full.

| # | Approach | Core idea | Why we dropped it | Branches |
|---|---|---|---|---|
| 1 | **Occupancy-grid SLAM + A\*** | build a world map, localise in it, plan a path each cycle | localisation never robust enough in the time we had | `path-planning`, `lidar-pose-estimation`, `test/path-lidar`, `field-visu` |
| 2 | **Follow-the-Gap (FTG)** | geometry-agnostic reactive steering toward the largest gap | smooth but imprecise; couldn't place the robot in a *lane* for obstacle passing | `path-planning` |
| 3 | **Reactive segment planner** *(current)* | assume the 4-straight/4-corner layout; gyro + LiDAR + per-pillar colour | — (this is what we run) | `segment-planners` → `main` |

## 1. Occupancy-grid SLAM + A\* planner

Our first full stack treated the problem as **map-build + localise + plan**, the classic
autonomous-driving pipeline — preserved in the git history (the `path-planning`,
`lidar-pose-estimation`, and `test/path-lidar` branches). The pieces:

- **`FieldMap`** — a 1200 × 1200 @ 5 mm/cell **occupancy grid** (log-odds) plus a semantic
  grid and an obstacle list, all updated from the LiDAR by a Bresenham ray-march.
- **`EgoInformation` EKF** with a LiDAR `[x, y, heading]` correction step, so the robot could
  place itself in the map (scan-matching lived on `lidar-pose-estimation` /
  `lidar-rework` as `LidarPoseEstimator`, merged into `test/path-lidar`).
- **`SemanticClassifier`** — DBSCAN clustering + RANSAC line fitting to label cells as wall /
  obstacle / parking wall; **`DirectionDetector`**; **`CollisionGuard`** as a raw-scan safety
  layer.
- **`PathPlanningProcessor`** — ray-cast goal selection → clearance-weighted, colour-aware
  **A\*** → line-of-sight path thinning → pure-pursuit lookahead, at 5 Hz. Lap 1 planned
  reactively and recorded a breadcrumb route; laps 2–3 followed the memorised route.

**Why we dropped it.** The whole stack stands on **accurate localisation**, and we could not
get the map + EKF pose reliable enough on the real track within the schedule. Drift in the
pose corrupts the occupancy grid, which corrupts the plan — a failure that is hard to debug
and harder to trust in a one-shot competition run. It was a lot of machinery to keep
calibrated.

## 2. Follow-the-Gap (FTG)

To escape the localisation problem we went **map-free**: a geometry-agnostic reactive
controller that steers toward the largest gap in the LiDAR scan, fused with a black-wall
memory. It needs no world position and no assumption about the track — it just drives down
whatever corridor is open, clockwise or anti-clockwise.

**Why we dropped it.** FTG drives a smooth centre-of-corridor line, but the obstacle
challenge needs the robot to sit in a **specific lane** to pass a pillar on the correct side
(red → right, green → left), and to do repeatable 90° corners. "Steer toward the gap" gives
no clean notion of *which lane am I in* or *where does this corner start*. It was the right
tool for the open challenge and the wrong one for obstacles.

## 3. Reactive segment planner (current)

The pivot (Aug 2026) was to **give up generality and exploit the known WRO layout**: a
rectangular loop of four straights and four 90° corners. That single assumption buys
determinism — the planner always knows it is on a straight or in a corner, which lane it
holds, and how many corners it has done. Localisation shrinks to a **principal angle** (grid
orientation from the walls) plus **lane dead-reckoning**, both of which are cheap and
self-correcting. The live code and its state machine are the
[processors chapter](../../src/rpi/processors/README.md).

Even within this approach a lot changed on hardware — the interesting pivots, all
reconstructed from `.h5` [recordings](../../src/rpi/recording/README.md):

- **Corner maneuvers: closed-loop → open-loop → hybrid.** Corners first used a closed-loop
  LiDAR **settle** onto the corridor centre. That was replaced by fully **open-loop scripted**
  recipes (tuned to land centred) to remove a fragile two-wall centering that spun the robot
  at a corner's open mouth — then partly **restored**: investigation of the recordings showed
  the old corner was precise *because of the settle, not the turn* (the arc always
  overshoots), so a closed-loop **rear-wall align** step went back in. The corner is now one
  scripted state ending in that align step.
- **Arc precision = anticipation, not slowing.** Because the planner re-emits the target every
  scan, the firmware's arrival-decel never fires and the arc coasts past the target. Slowing
  the arc hit the motor deadband and stalled; the fix was to terminate each arc a **lead
  angle** early so the coast lands it on target.
- **Lane switches and the 45° "grid flip".** Early lane switches could yaw the robot past 45°
  off the segment, at which point `segment_heading` snapped to the next grid line and the
  switch oscillated forever. Fixed structurally by **latching the grid line per straight**
  (`seg_k`) so it can no longer snap, after which the switch was redesigned to "drive beside
  the pillar."
- **Parking-slot start: detect → declare.** Auto-detecting a parked start kept confusing the
  corner for the exit, so it became an **explicit operator flag** (`--parking-start`) with the
  exit side **voted** over a few scans.
- **Firmware reverse geometry.** A subtle one: the firmware resets its frame on every
  `setTarget`, so a reverse target with a fixed lateral offset is re-chased each scan and the
  robot rotates unbounded. Straight reverses must therefore be **lateral = 0**; intentional
  rotation-while-reversing is the reverse-**arc** turn, gyro-terminated and distance-capped.

These are the kind of hardware-only failure modes that no amount of simulation surfaces — the
reason the [recording framework](../../src/rpi/recording/README.md) exists.

---

*A hardware pivot worth noting alongside these: the Pi↔Arduino link was originally a 10-wire
level shifter and is now a single USB cable — see
[Processing Units](../hardware/processing-units.md).*

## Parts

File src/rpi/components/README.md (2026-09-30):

# Components — hardware drivers

Components are the robot's hardware drivers. Each one wraps a single device, runs its own
background daemon thread, and fires an [`Event`](../utils/Event.py) when fresh data is ready.
They sit at the bottom of the Raspberry Pi software; everything else subscribes to their
events. See the [architecture overview](../../../docs/software/architecture.md) for how they
fit together.

## The `Component` lifecycle

Every component inherits from [`Component`](Component.py) and shares one lifecycle, so they
are all started, stopped, and cleaned up the same way:

| Step | Method | What happens |
|---|---|---|
| open | `__enter__` → `_setup()` | open the serial port / camera; on failure `_teardown()` runs and the error re-raises, so a half-open device is never leaked |
| run | `start()` → `_run()` | launch the background daemon thread |
| stop | `stop()` | signal the thread, join it (3 s timeout) |
| close | `__exit__` → `_teardown()` | release the hardware |

In the mains, components are opened inside an `ExitStack`, so a failure part-way through
setup unwinds everything already opened. A component fires its event **on its own thread**;
subscribed handlers therefore run there too (see the [event model](../../../docs/software/architecture.md)).

## `Lidar` — [`Lidar.py`](Lidar.py)

Drives the RPLIDAR A2M8 over serial (`adafruit_rplidar`). The thread reads individual
measurements and buffers them; on each **new full rotation** it fires `on_scan` with a
NumPy array of shape `(N, 3)` — `(angle_rad, distance_mm, quality)` — for every valid
return in that rotation. Zero-quality and zero-distance returns are dropped before the event
fires. The spinner PWM is set to `660`. A `RPLidarException` (e.g. a USB hiccup) flushes the
serial buffer and retries after a short pause, so transient disconnects recover on their own.

| | |
|---|---|
| Port | `/dev/lidar` (udev symlink) |
| Baud | 115200 |
| Scan mode | normal |
| Event | `on_scan(scan: np.ndarray[N,3])` |

## `Camera` — [`Camera.py`](Camera.py)

Captures frames from the USB camera with OpenCV `VideoCapture`. Each frame is rotated 180°
(the camera is mounted upside down) and handed to `on_frame` as a BGR array. If reads fail
60× in a row the capture loop stops rather than spinning forever. The camera is optional:
`main_obstacle.py --no-camera` skips it entirely.

| | |
|---|---|
| Device | index `0` |
| Resolution | 640 × 480 |
| Target FPS | 30 |
| Event | `on_frame(frame: np.ndarray)` |

## `Arduino` — [`Arduino.py`](Arduino.py)

Manages the framed UART link to the Arduino Nano. The background thread reads bytes, parses
the protocol, and fires `on_state` on each valid `STATE` frame. Two thread-safe send methods
are exposed to the rest of the system:

- `set_target(forward_mm, lateral_mm, speed)` → a `SET_TARGET` frame (body-frame pursuit
  point; negative `speed` = reverse).
- `stop()` → a `STOP` frame (immediate halt).

The wire format — start byte `0xAA`, `MSG_ID`, `LEN`, payload, CRC-8 (poly `0x07`) — is the
mirror of the firmware's [`Protocol`](../../arduino/README.md#protocol--framed-uart); this
file is the Python half. `STATE` carries `(heading_rad, speed_mm_s, steering_rad,
distance_mm)`.

| | |
|---|---|
| Port | `/dev/arduino` (udev symlink) |
| Baud | 115200 |
| Send | `set_target(...)`, `stop()` |
| Event | `on_state(heading, speed, steering, distance)` |

## Adding a component

Subclass `Component`, expose an `Event`, open the device in `_setup`, release it in
`_teardown`, and fire the event from `_run`. Nothing else has to change: subscribers
(planner, recorder, visualizer) attach with `+=`.

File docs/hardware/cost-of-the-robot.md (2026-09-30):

# Cost of the Robot

| Product name | Price (HUF) | Price (EUR) |
|---|---|---|
| Raspberry Pi 5 8GB | 69 990,00 | 191,75 |
| AR-NANOCH-UNS-TYPE-C | 1 992,45 | 5,45 |
| BNO055 | 17 990,00 | 49,28 |
| DRV8871-MK | 1 758,91 | 4,81 |
| DFRobot FIT0701 | 3 042,95 | 8,33 |
| RPLIDAR A2M8 | 98 065,86 | 268,67 |
| DSN-1504-3A | 444,11 | 1,21 |
| MINI560-5V-5A | 1 457,76 | 3,99 |
| INR EVE 18650 | 3 000,00 | 8,21 |
| BMS 3S 20A | 541,09 | 1,48 |
| HS-485HB | 8 918,16 | 24,43 |
| N20E-12-500 | 4 370,7 | 11,97 |
| LEGO Wheels | 1 932,00 | 5,29 |
| ST 1/BK | 250,10 | 0,68 |
| PBS-110-NO-BK | 294,22 | 0,8 |
| **Total** | **214 048,31** | **586,43** |

*Exchange rate: 1 EUR = 365 HUF*

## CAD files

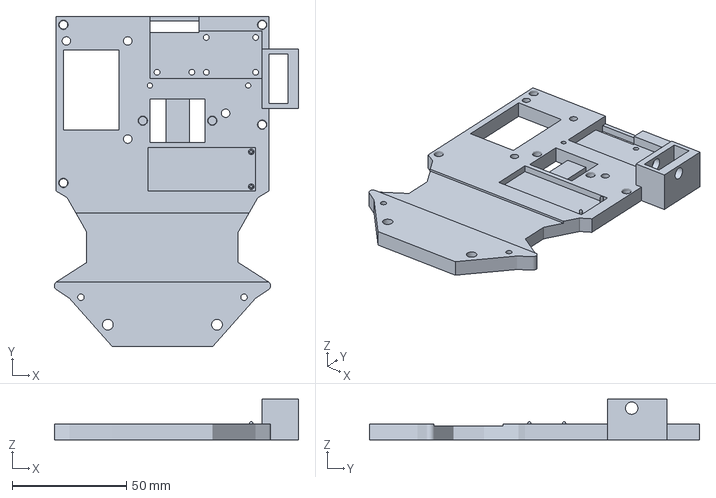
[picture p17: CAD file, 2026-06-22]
models/baseplate_bottom.3mf
107.0 x 144.4 x 17.9 mm

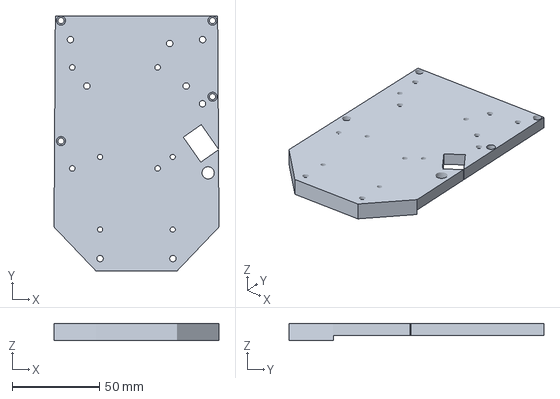
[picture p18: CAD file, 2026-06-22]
models/baseplate_top.3mf
94.8 x 146.4 x 10.0 mm

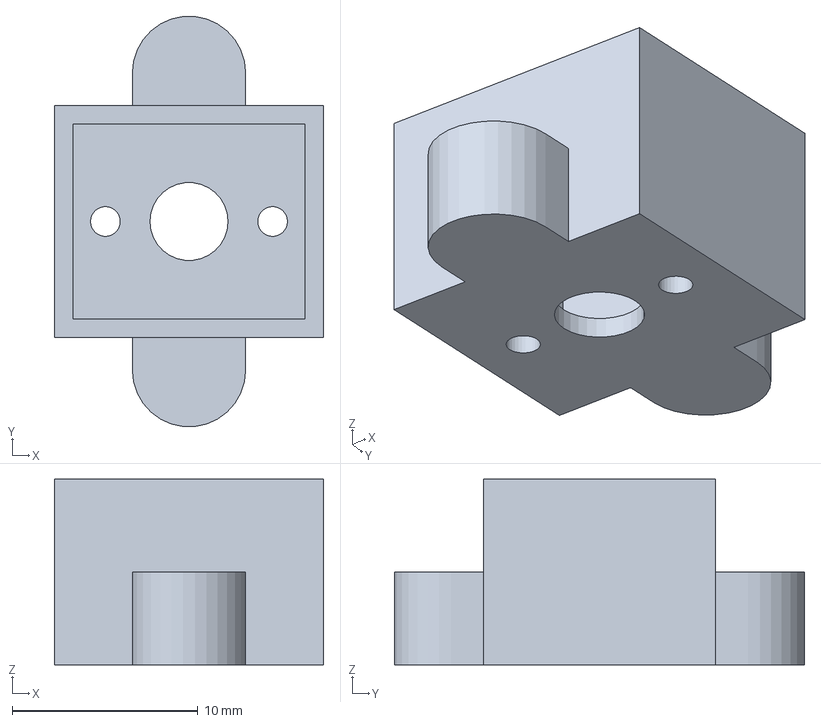
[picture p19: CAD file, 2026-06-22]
models/DC_hub.3mf
14.5 x 22.1 x 10.0 mm

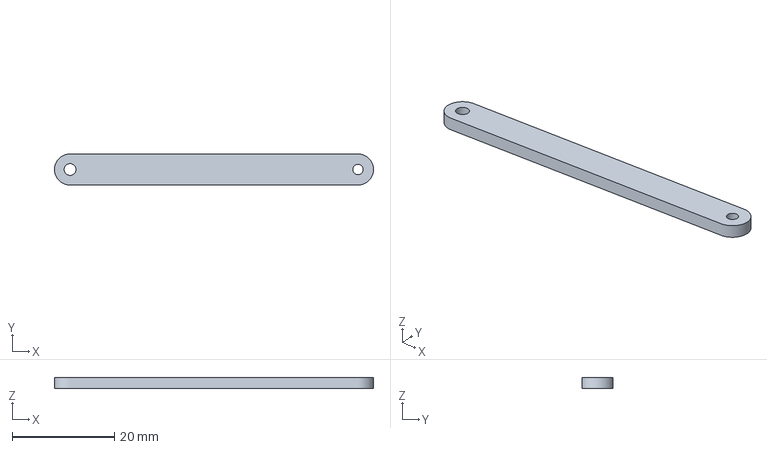
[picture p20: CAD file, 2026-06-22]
models/steering_link.3mf
62.3 x 6.08 x 2.20 mm

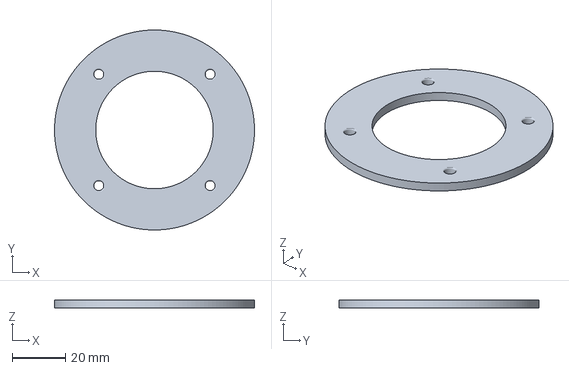
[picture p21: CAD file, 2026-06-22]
models/Lidar_holder.3mf
74.9 x 74.9 x 3.00 mm

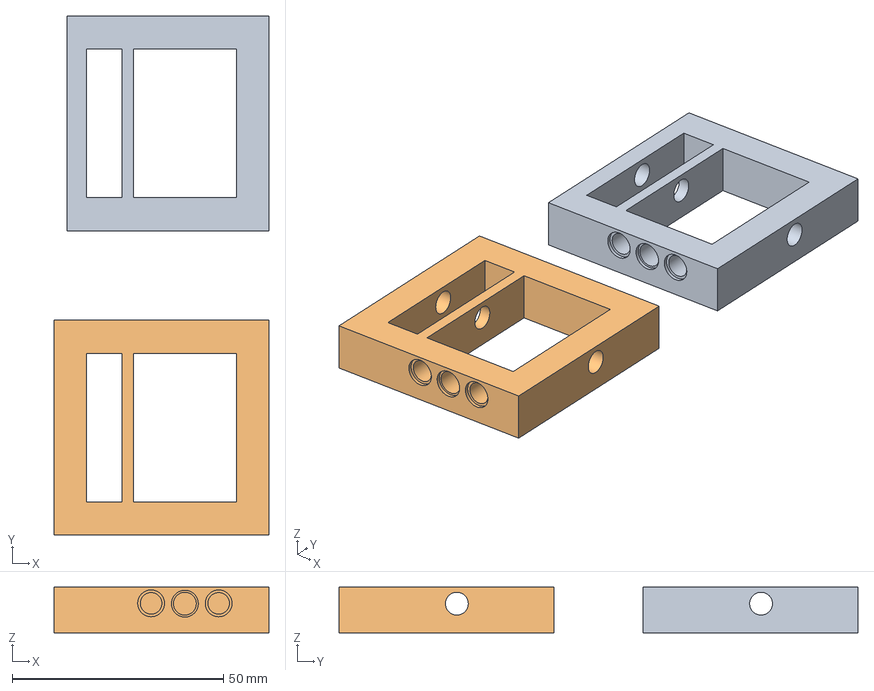
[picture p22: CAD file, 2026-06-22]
models/differential_housing.3mf
50.8 x 122.8 x 10.9 mm

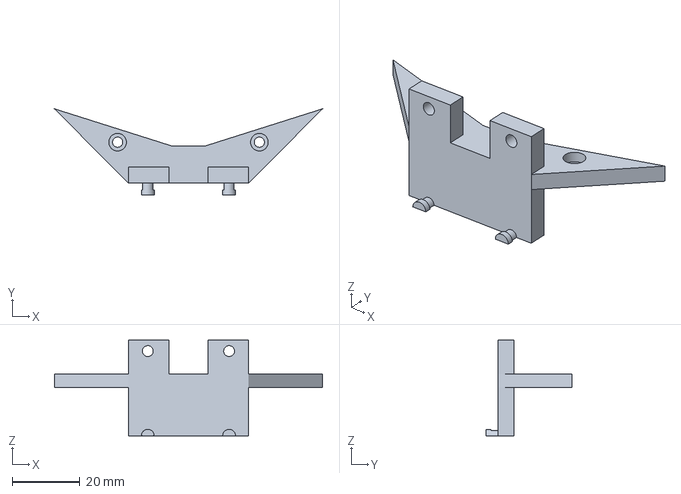
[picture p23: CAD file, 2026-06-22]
models/cam_holder.3mf
79.1 x 25.5 x 28.2 mm

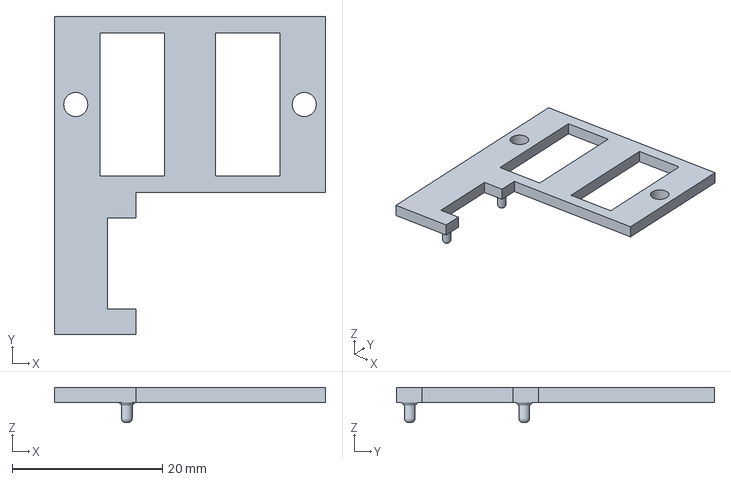
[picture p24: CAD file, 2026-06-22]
models/arduino_holder.3mf
36.1 x 42.3 x 4.70 mm

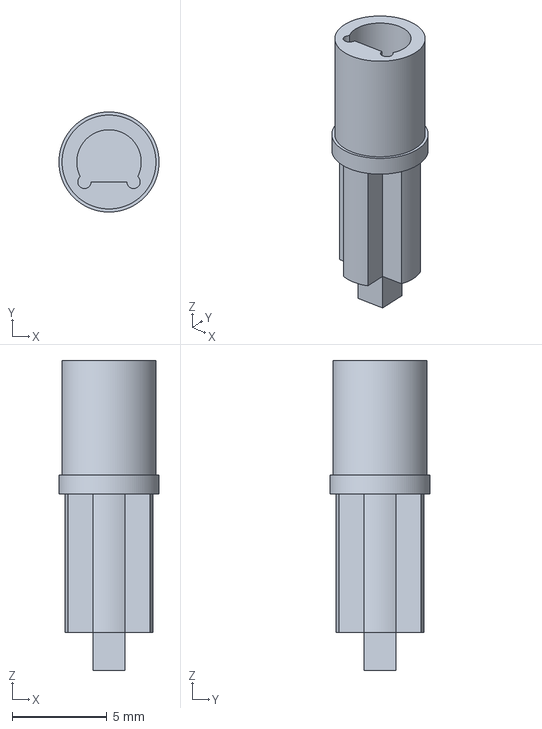
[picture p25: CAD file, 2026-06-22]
models/DC_axle.3mf
5.28 x 5.28 x 16.4 mm

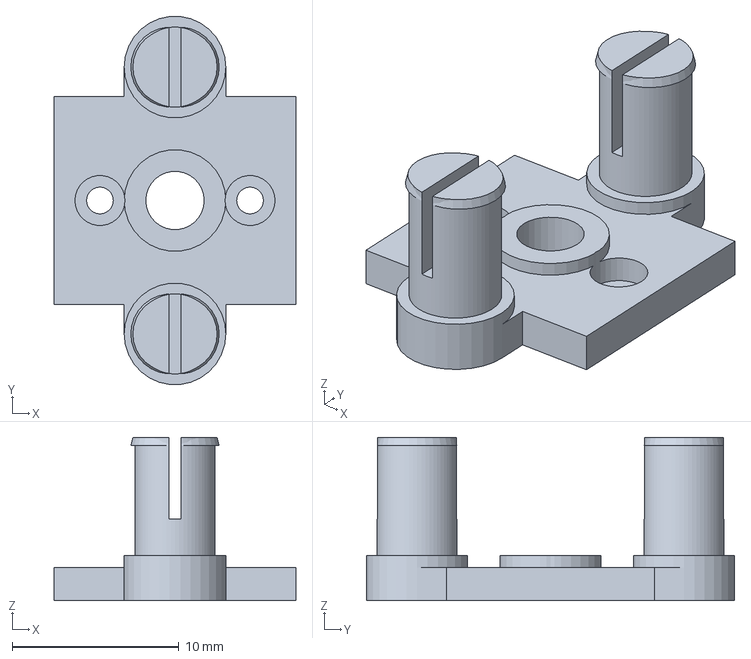
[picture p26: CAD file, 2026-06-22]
models/DC_front_mount.3mf
14.5 x 22.1 x 9.80 mm

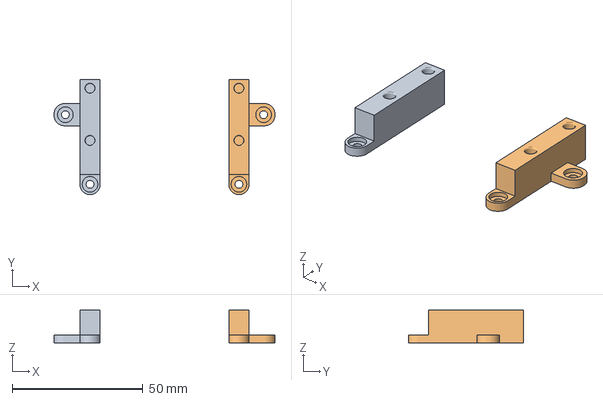
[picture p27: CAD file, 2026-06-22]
models/battery_holder.3mf
84.6 x 44.2 x 12.5 mm

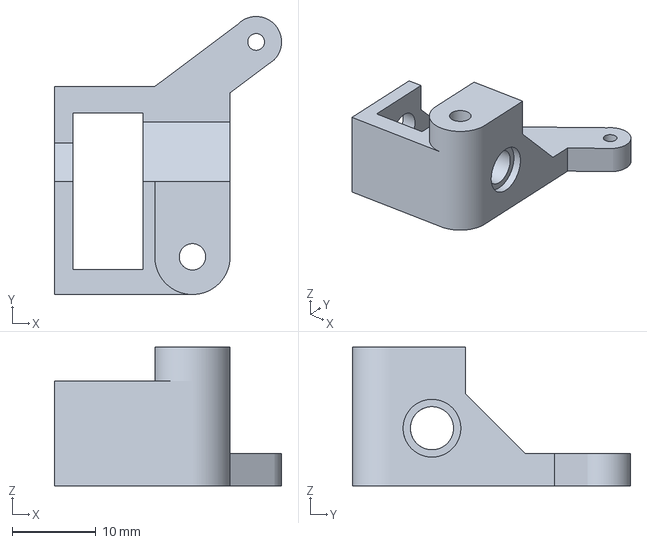
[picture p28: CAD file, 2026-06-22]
models/steering.3mf
27.2 x 33.2 x 16.6 mm

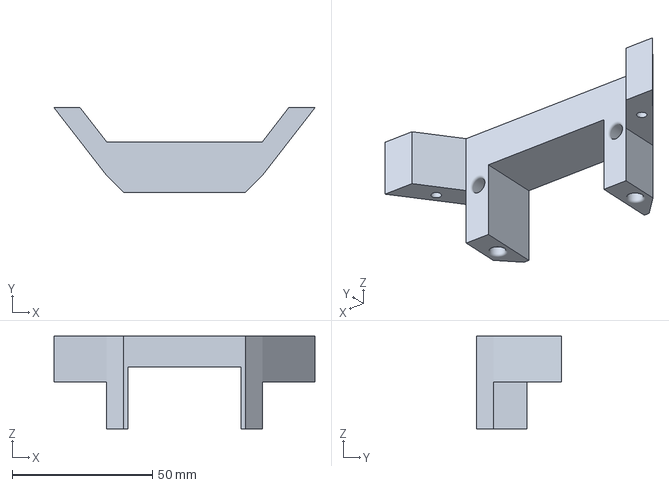
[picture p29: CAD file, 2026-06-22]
models/servo_holder.3mf
93.0 x 30.1 x 33.0 mm

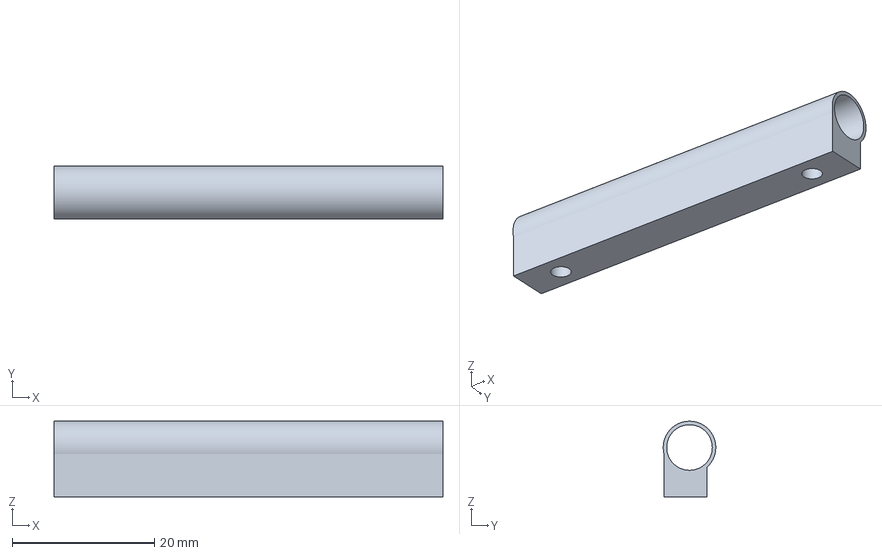
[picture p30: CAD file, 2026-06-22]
models/axle_cover.3mf
54.7 x 7.40 x 10.6 mm

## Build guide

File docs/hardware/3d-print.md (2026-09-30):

# 3D Print

## Printer Selection

The Bambu Lab P1S FDM printer was selected for this project to enable systematic material experimentation and validation across multiple types of filaments. The printer's fully enclosed thermal chamber provides precise temperature regulation, minimizing warping and ensuring dimensional consistency across production runs.

### Key Specifications

- Fully enclosed heated chamber with active thermal management
- Multi-material capability (PLA, PETG, ASA, ABS)
- High positional accuracy suitable for mechanical assemblies

## Material Strategy

A three-stage material selection approach was employed:

### Prototyping Phase

**Material:** PLA

- Used for rapid iteration and design validation
- Lower processing temperature reduces printer stress during concept testing

### Production Phase

Two materials were selected for the final assembly based on functional requirements:

#### ABS

**Application:** Thermal-critical components (e.g., Raspberry Pi 5 mounting plate)

- Superior heat resistance and thermal stability
- Upper service temperature: ~80–100 °C continuous operation
- ABS was selected to provide a substantial safety margin and ensure thermal resilience under worst-case scenarios without risk of material softening or creep

#### PETG-HF (High-Flow PETG)

**Application:** Functional mechanical assemblies (differential gearbox housing, servo mount)

- Enhanced layer adhesion and impact resistance compared to standard PETG
- Adequate thermal resistance for non-critical zones
- Superior dimensional retention and reduced creep under cyclic loading
- **Justification:** PETG is highly durable and tends to bend slightly rather than shatter under stress. This makes it ideal for parts that endure drops, vibrations, or repeated wear. The layer adhesion is also exceptional and parts are less prone to splitting along weak seams when under load.

## Quality Assurance

All printed components underwent:

- Visual inspection for layer uniformity and surface finish
- Dimensional verification against CAD models (tolerance stack-up analysis)
- Mechanical fit testing of assemblies prior to integration

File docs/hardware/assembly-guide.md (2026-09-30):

# Assembly Guide

Print out each part with the right material:

- Top and bottom plates: ABS
- Every other part: PETG

For printing out the parts we used the base Bambu settings, since they're already decent enough.

**Important Note** Use a soldering iron to put the inserts into the 3D printed parts based on the pictures given.

**Recommended temperatures**
- PLA: 130 °C
- PETG: 180 °C
- ABS: 200 °C

**Legend**
- Blue: Part name
- Red: Size of the inserts and screws

**Tip**

If the printed parts come apart parallel to the layers, then try to print them using a 35-55°  tilt or a different infill pattern, which will give it more structural rigidity.

# Pictures

## Bottom Plate

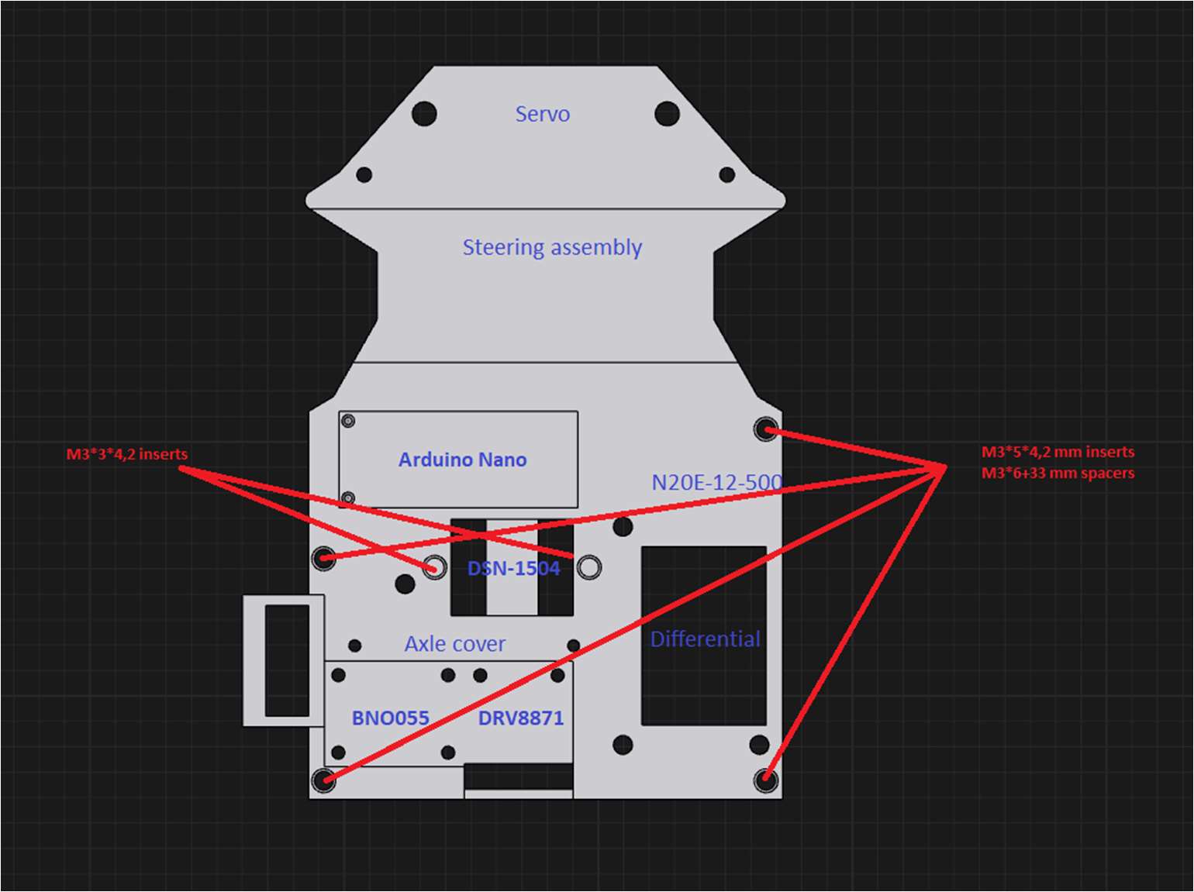
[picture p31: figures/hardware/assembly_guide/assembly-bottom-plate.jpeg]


## Differential Housing

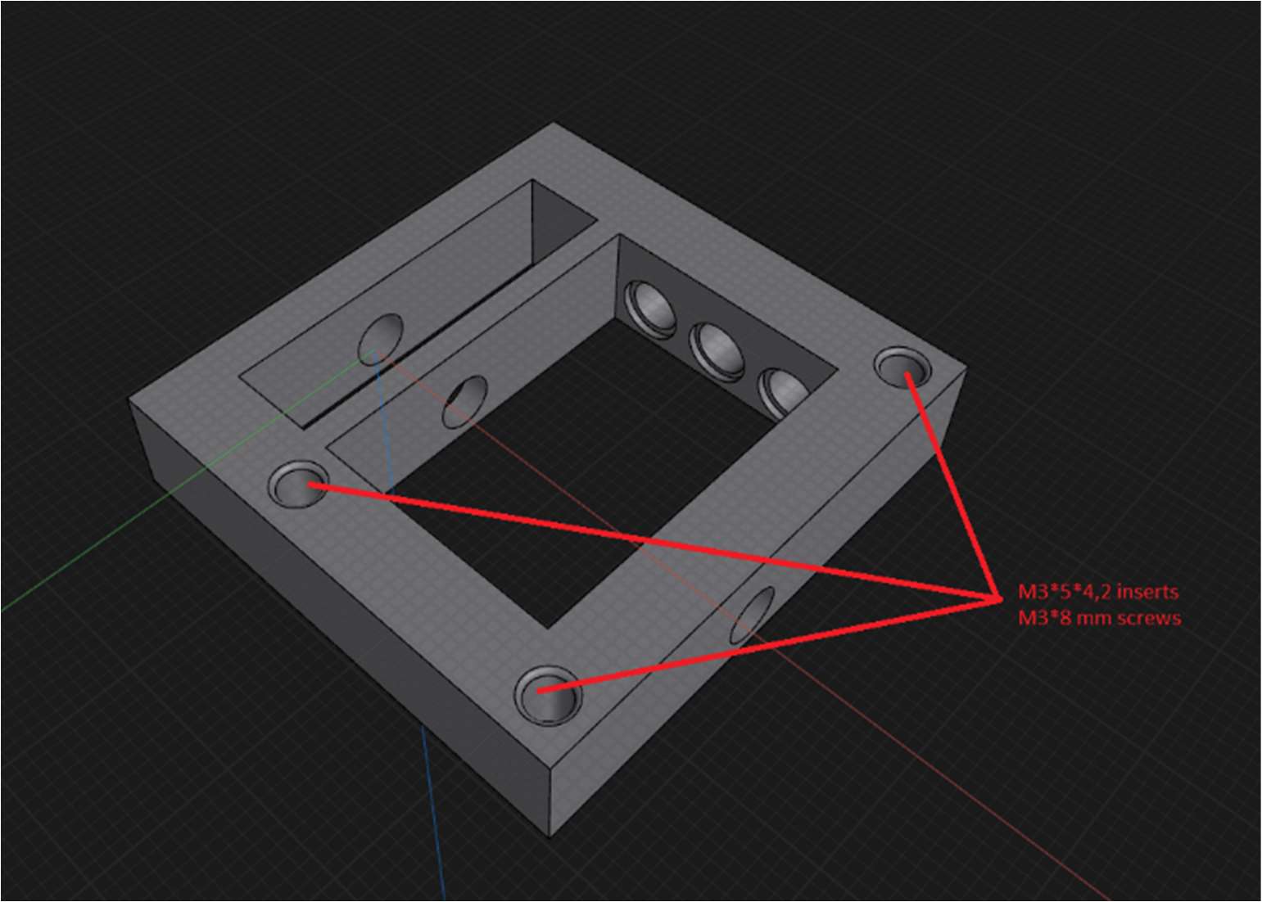
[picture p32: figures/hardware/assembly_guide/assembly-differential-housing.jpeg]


## Servo Holder

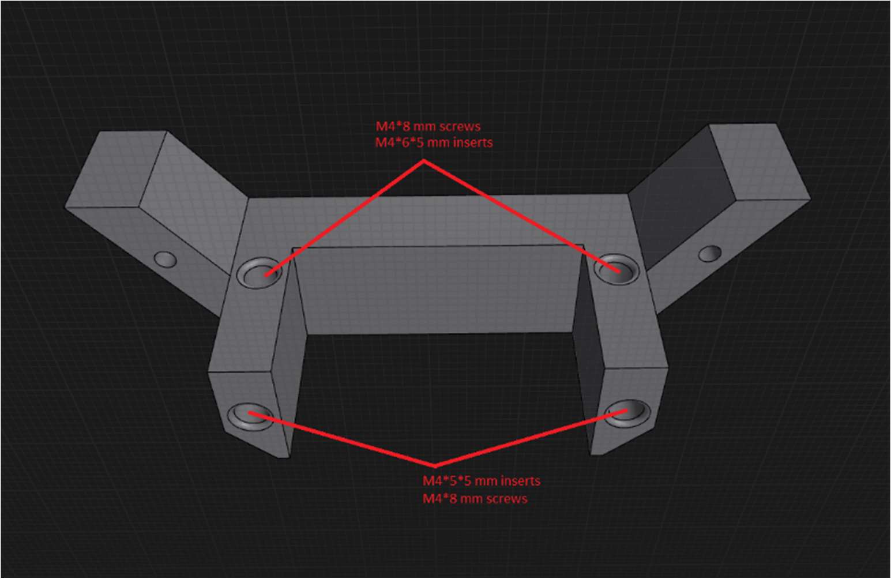
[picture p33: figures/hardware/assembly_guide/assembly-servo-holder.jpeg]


## DC Assembly

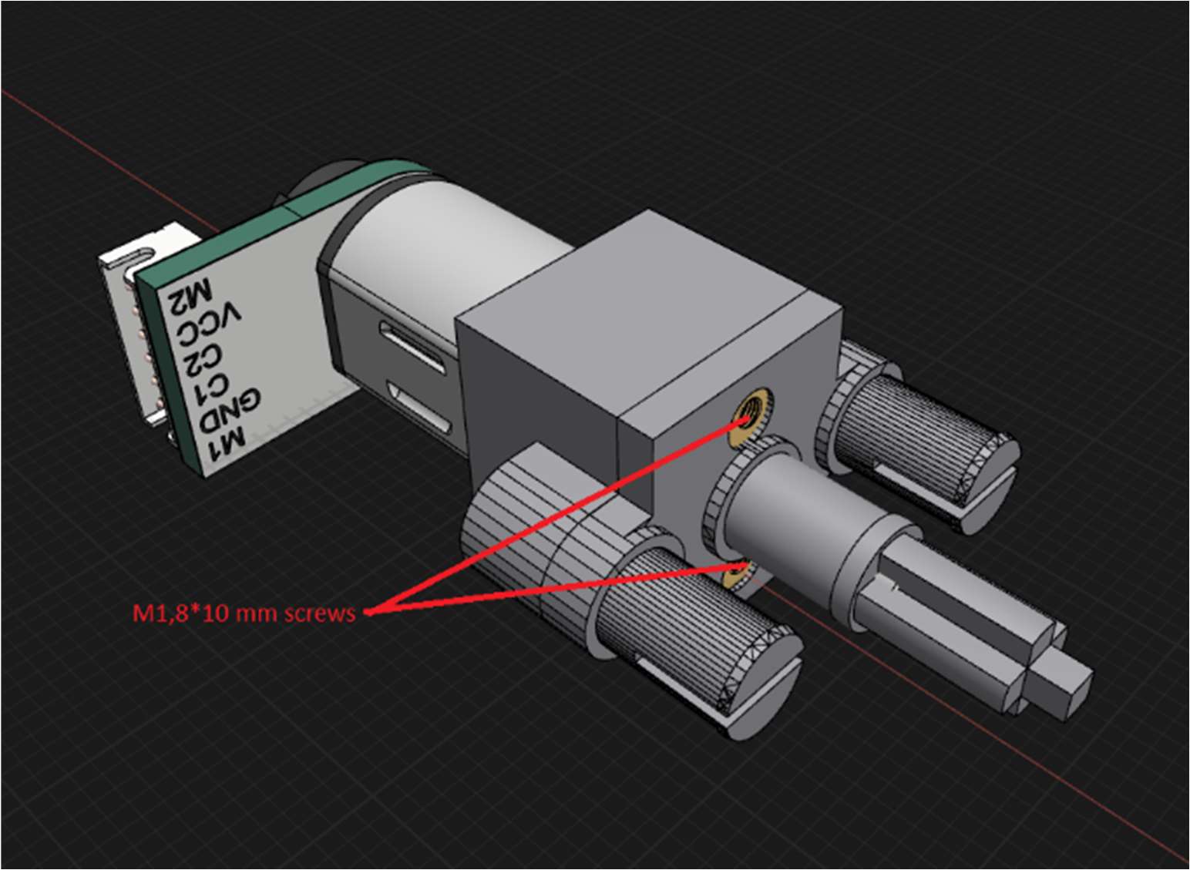
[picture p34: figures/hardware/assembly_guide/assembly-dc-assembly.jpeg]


## Arduino Holder

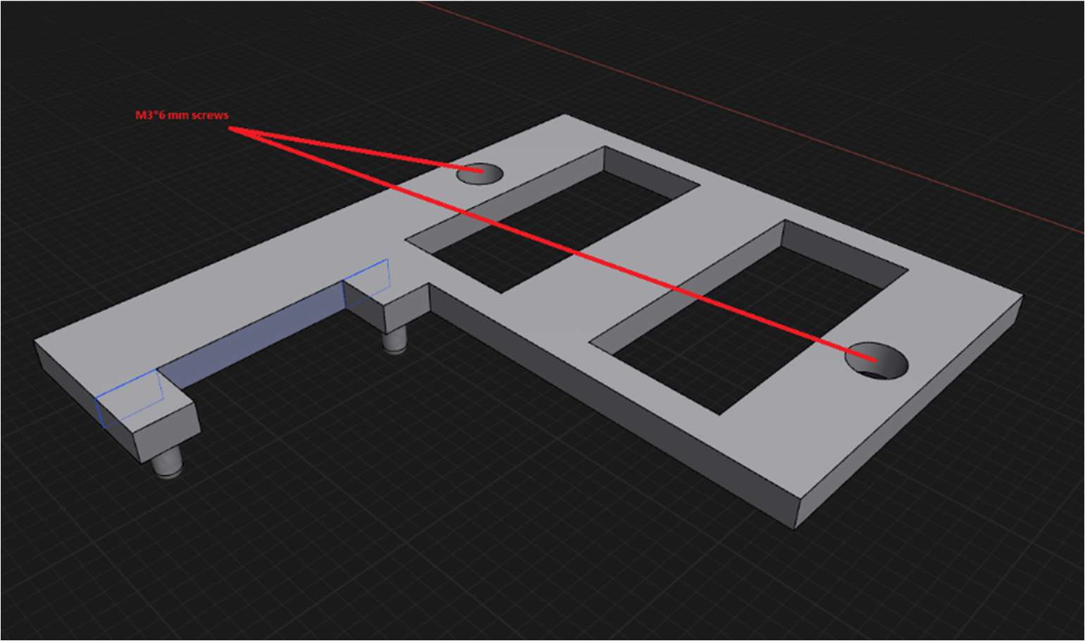
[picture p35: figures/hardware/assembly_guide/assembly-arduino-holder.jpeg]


## Axle Cover

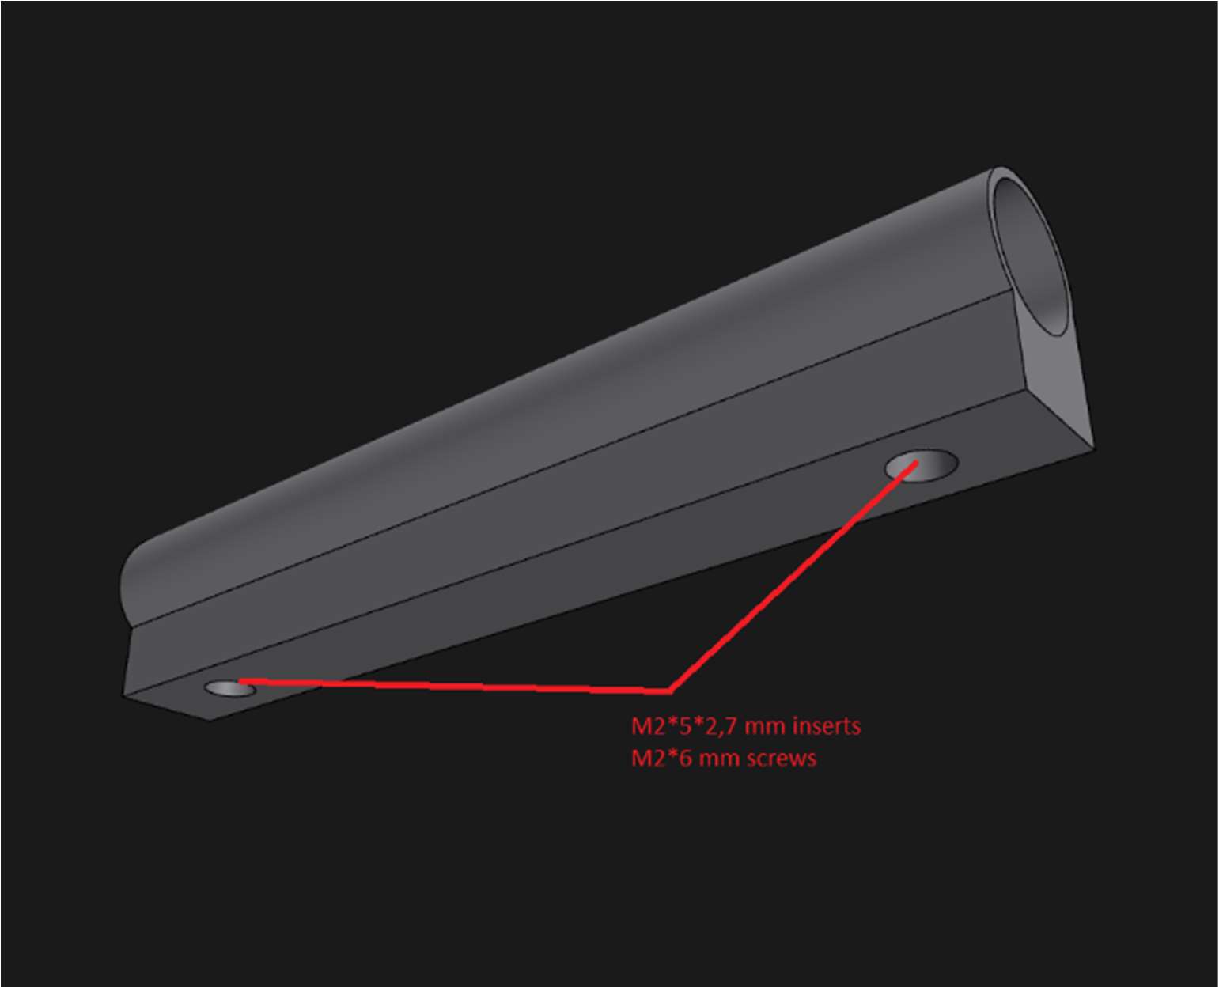
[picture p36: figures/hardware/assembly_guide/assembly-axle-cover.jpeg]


## Steering Assembly

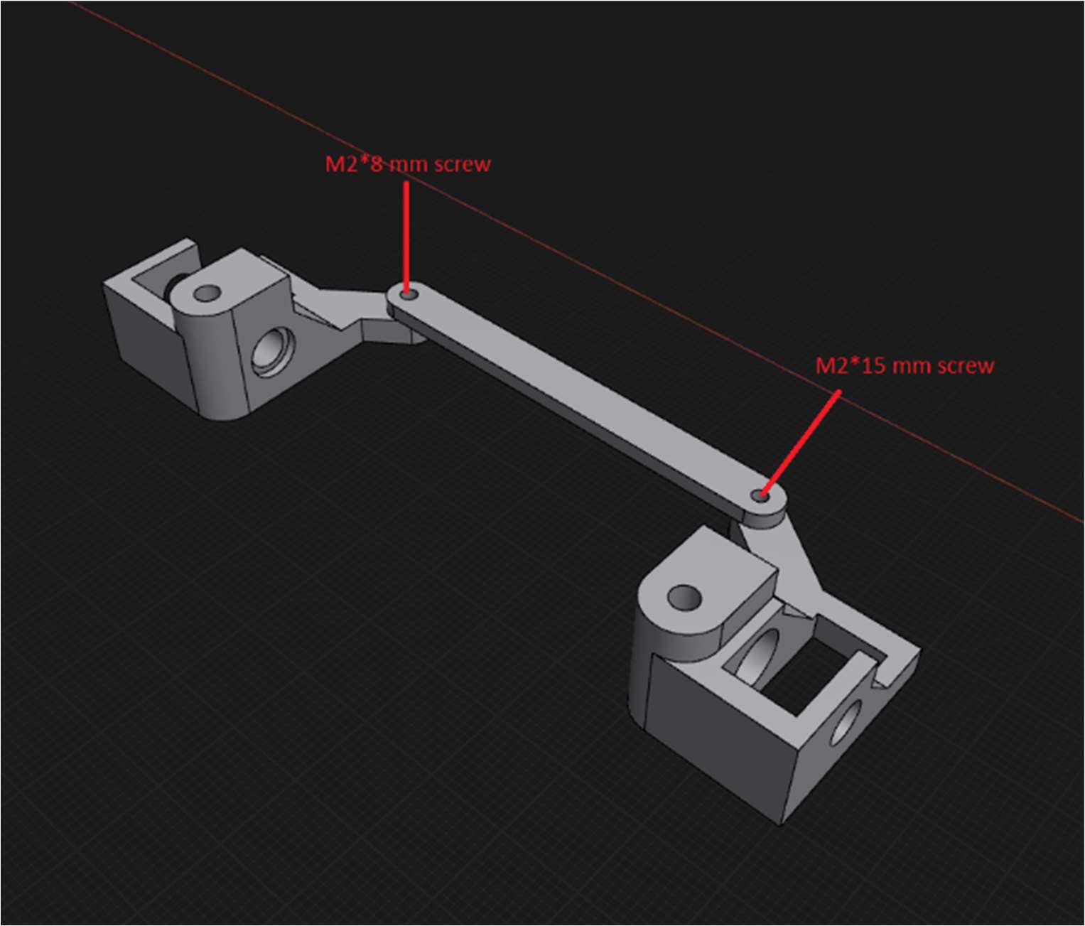
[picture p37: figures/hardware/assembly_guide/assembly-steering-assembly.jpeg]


## Fully Assembled Bottom Part

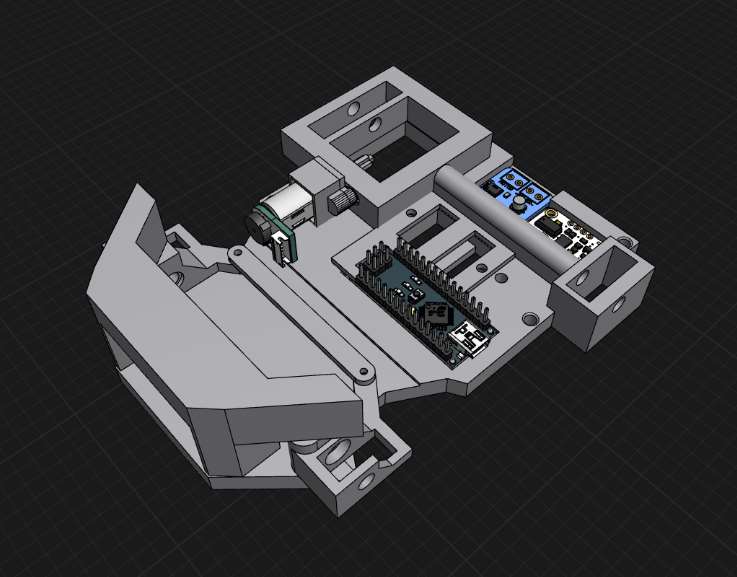
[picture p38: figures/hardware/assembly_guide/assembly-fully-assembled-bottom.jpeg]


## Top Plate

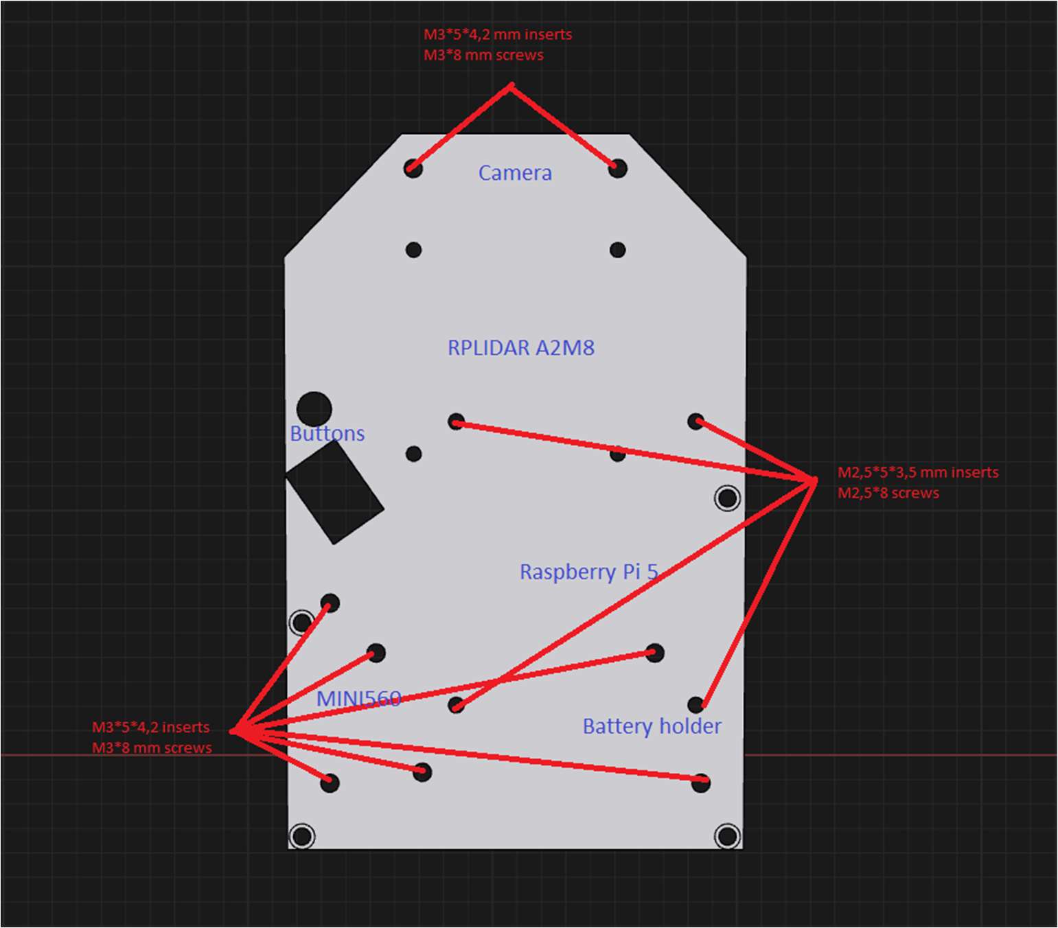
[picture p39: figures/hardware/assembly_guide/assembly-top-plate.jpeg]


## Lidar Holder

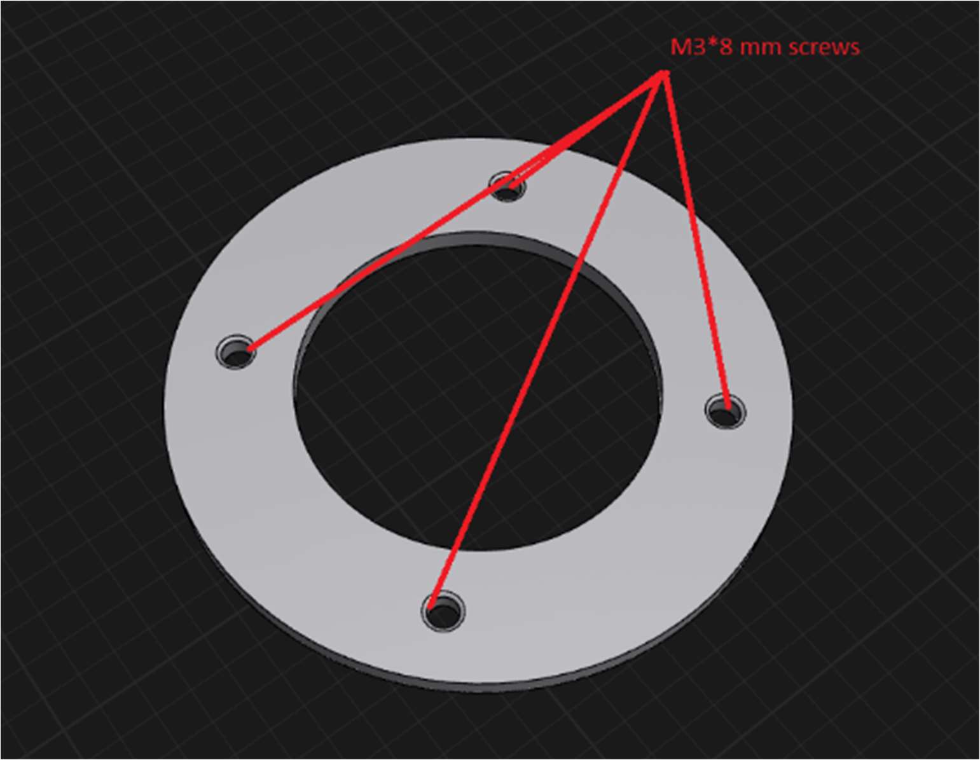
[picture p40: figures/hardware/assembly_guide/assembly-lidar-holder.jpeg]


## Stepdown Holder

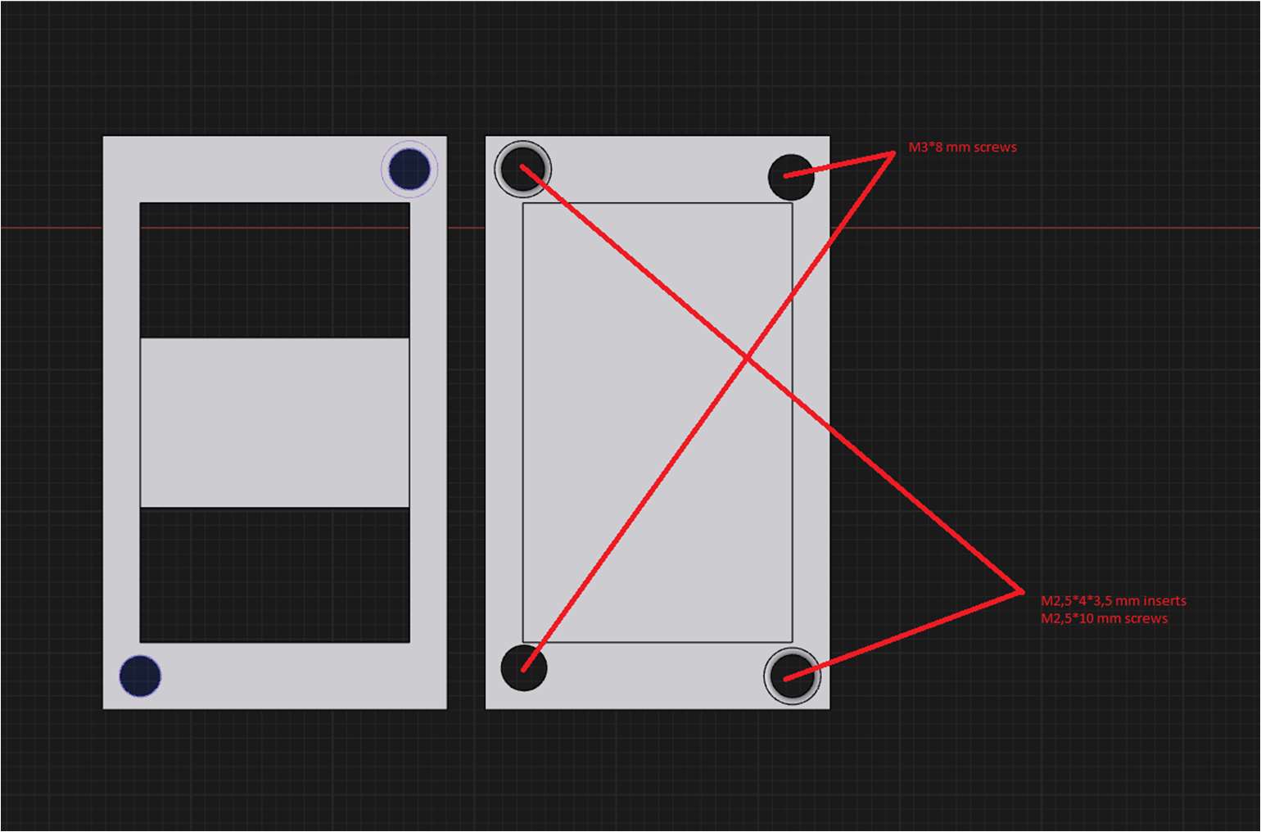
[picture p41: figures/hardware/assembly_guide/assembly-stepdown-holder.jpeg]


## Cam Holder

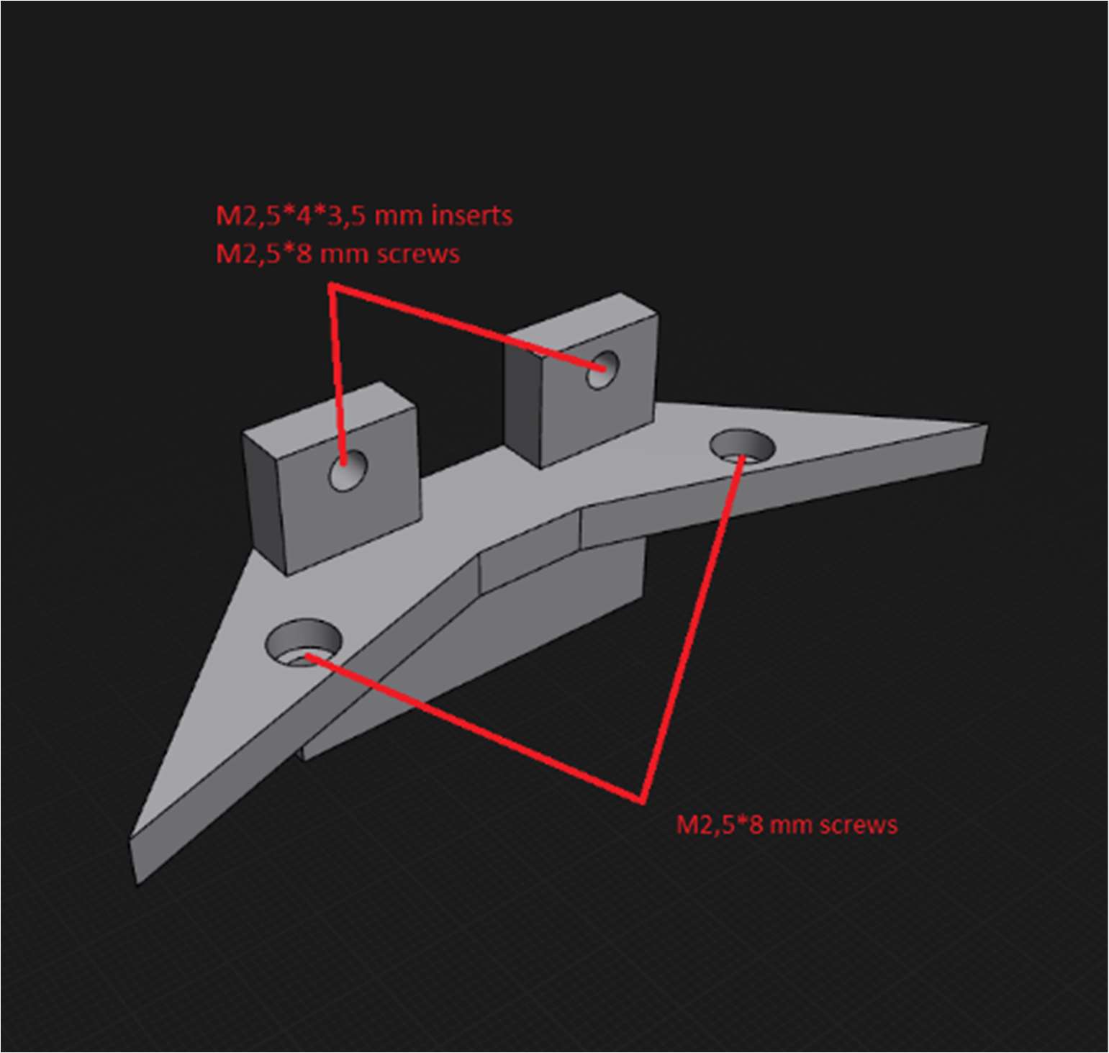
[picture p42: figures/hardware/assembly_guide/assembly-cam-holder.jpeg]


## Battery Holder

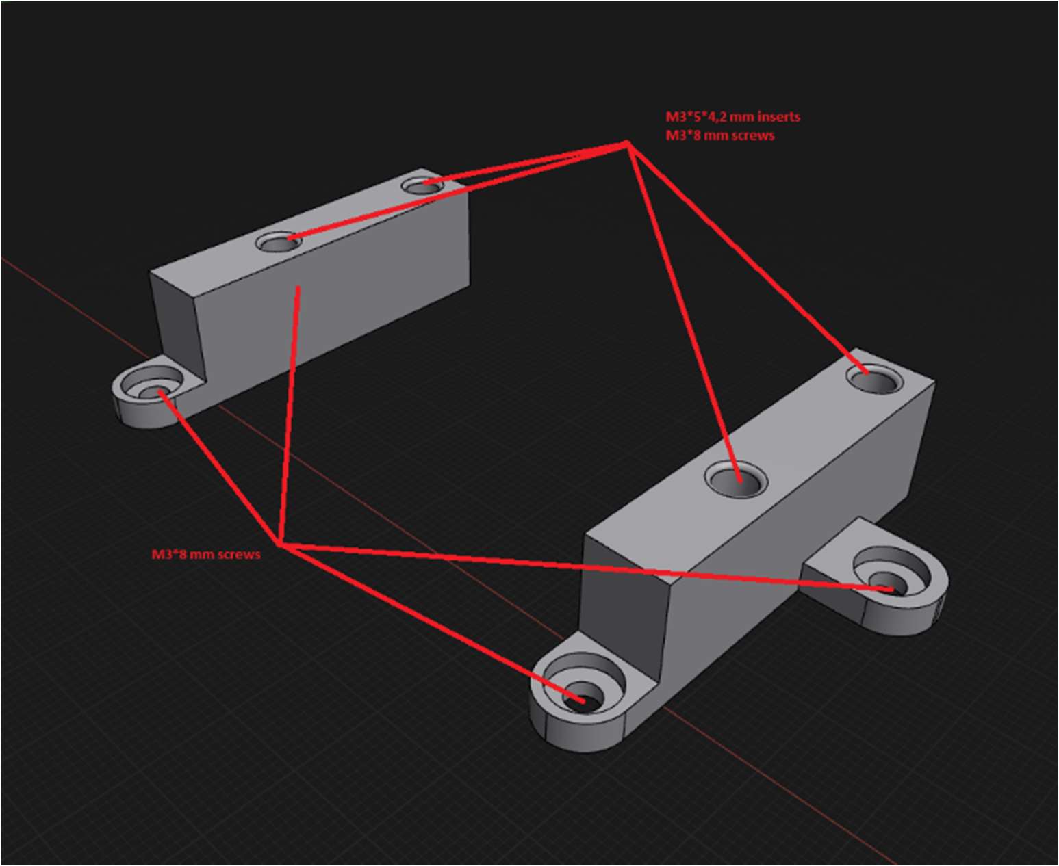
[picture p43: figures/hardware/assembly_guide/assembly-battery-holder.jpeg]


## Assembled Robot

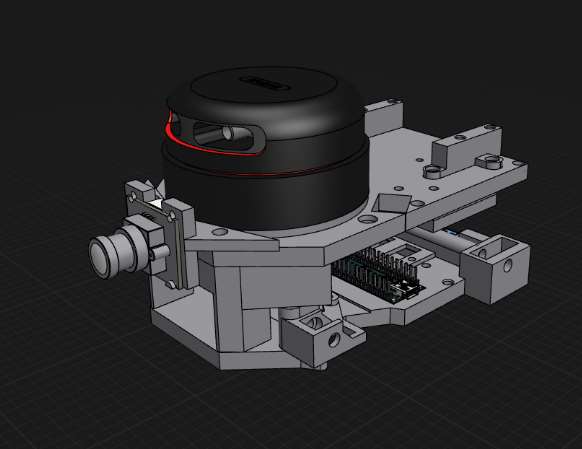
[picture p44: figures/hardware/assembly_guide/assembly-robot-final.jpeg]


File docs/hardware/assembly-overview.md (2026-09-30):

# Assembly Overview

Our robot utilizes positive Ackermann steering geometry, differential drive, and a multi-plate design.

### Chassis Architecture: Multi-Plate Design

The robot employs a dual-plate chassis architecture, separating the vehicle into two functional layers connected by standoffs: a bottom plate and a top plate.

- **Top plate** — carries the sensor suite responsible for perception (vision) and the battery pack.
- **Bottom plate** — houses the complete drive system (drive motor, differential, motor controller, IMU) along with the steering mechanism, which uses positive Ackermann geometry paired with differential drive on the rear axle.

This functional separation was a deliberate design choice: by isolating the drivetrain and its associated electronics from the sensor and power systems, individual subsystems can be accessed, diagnosed, and repaired independently without requiring disassembly of the entire chassis. This modularity reduces downtime during testing and competition, where rapid fault isolation and repair are critical.

### Ackermann Steering

Ackermann steering geometry is a geometric arrangement of linkages in the steering of a car or other vehicle designed to solve the problem of wheels needing to trace circles of different radii when turning.

**The problem it solves**
When the robot turns into a corner, the inside wheels travel along a tighter path than the outside wheels. Because the inside wheel is closer to the center of the turn, it must turn at a sharper angle than the outside wheel. If both wheels turned at the exact same angle, the tires would scrub, slide sideways, and cause unnecessary wear and tear.

**How it works**
Ackermann steering achieves the correct angles by angling the steering arms inward.

- *The alignment*: If you draw a line from the steering knuckles (the pivot points of the wheels) through the tie-rod ends, those lines will intersect exactly at the center of the rear axle when the wheels are pointing straight ahead.
- *The dynamic*: When you turn the steering wheel, this angled linkage causes the inside wheel to turn more sharply than the outside wheel.

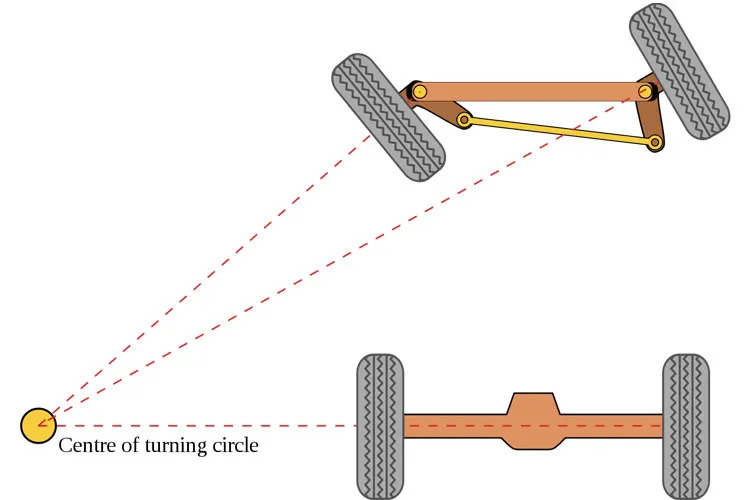
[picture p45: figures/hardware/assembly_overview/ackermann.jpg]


**The result**
By ensuring that all four wheels trace paths around a single, shared center point, the vehicle experiences smoother turning with minimal tire slippage or scrubbing — predictable handling and better directional stability.

### Differential Drive

Differential drive is used on the rear axle to allow the two rear wheels to rotate at independent speeds during turns. When the robot steers using the Ackermann-geometry front axle, the inner and outer rear wheels naturally need to travel different distances through a corner — the outer wheel traces a larger radius than the inner one. Without a differential, both wheels would be forced to rotate at the same speed, causing one wheel to scrub or skid against the mat's surface. This scrubbing introduces unpredictable friction losses and degrades the accuracy of odometry-based positioning, which is critical for autonomous navigation.

By allowing independent wheel speeds, the differential reduces mechanical stress on the drivetrain, improves traction and turning smoothness, and helps ensure that the robot's actual path more closely matches its commanded path — an important factor for precise, repeatable autonomous maneuvers.

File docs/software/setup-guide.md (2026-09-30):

# Developer & setup guide

How to set up, flash, run, and debug the robot from scratch. Placeholders like
`<pi-user>` / `<robot-host>` are things specific to your machine — fill them in for your
setup.

> Angle brackets = **fill this in**. Commands assume you are in the repository root unless a
> `cd` says otherwise.

## Prerequisites

- **Raspberry Pi 5** running Raspberry Pi OS (64-bit), with the LiDAR, camera, and Arduino
  connected over USB.
- **Python 3.13** on the Pi (the code uses `X | None` syntax and `from __future__`).
- **`arduino-cli`** (on whatever machine flashes the Nano), with the AVR core.
- **Git**.

## Repository layout

```
src/rpi/          Raspberry Pi software (Python)
  components/     hardware drivers            (README)
  control/        blackboard state            (README)
  processors/     algorithms + planner        (README)
  recording/      HDF5 signal recorder        (README)
  visu/           live web visualizers        (README)
  main_open.py    open-challenge entry point
  main_obstacle.py obstacle-challenge entry point
src/arduino/      Arduino Nano firmware (C++)      (README)
calibration/      one-time calibration scripts     (README)
recordings/       run_*.h5 files land here (git-ignored)
Makefile          flash the Arduino
```

The architecture is in [`docs/software/architecture.md`](architecture.md); each folder's
`README.md` documents its code.

## 1. Flash the Arduino

The [`Makefile`](../../Makefile) wraps `arduino-cli` (FQBN `arduino:avr:nano:cpu=atmega328`,
port `/dev/arduino`). One-time setup:

```bash
arduino-cli core install arduino:avr
arduino-cli lib install "Adafruit BNO055"        # pulls in Adafruit Unified Sensor + BusIO
```

Then, whenever the firmware changes:

```bash
make flash          # = compile + upload to /dev/arduino
# or separately:
make compile
make upload
```

If the Nano is a clone with the old bootloader, change the FQBN in the `Makefile` to
`...:cpu=atmega328old`. Firmware details: [Arduino firmware chapter](../../src/arduino/README.md).

## 2. Raspberry Pi Python environment

```bash
cd src/rpi
python3 -m venv .venv
source .venv/bin/activate
pip install -r requirements.txt
```

`requirements.txt` pins the hardware libraries (`pyserial`,
`adafruit-circuitpython-rplidar`, `adafruit-blinka`, `lgpio`, `gpiozero`) and the compute
stack (`numpy`, `scipy`, `scikit-learn`, `h5py`, `opencv-python`, `matplotlib`). `gpiozero`
+ `lgpio` drive the start button on BCM pin 17.

The [calibration scripts](../../calibration/README.md) use a **separate** environment
(`calibration/requirements.txt`) — set it up the same way inside `calibration/`.

## 3. Device symlinks (`/dev/lidar`, `/dev/arduino`)

The code opens the LiDAR and Arduino by **stable names** (`/dev/lidar`, `/dev/arduino`)
rather than `/dev/ttyUSB*`, which reorder on reboot. These are udev symlinks created on the
Pi (they are **not** in the repo). Find each device's attributes:

```bash
udevadm info -a -n /dev/ttyUSB0 | grep -E 'idVendor|idProduct|serial' | head
```

then create `/etc/udev/rules.d/99-robot.rules` (fill in from the output above):

```udev
# RPLIDAR (CP210x USB-serial)
SUBSYSTEM=="tty", ATTRS{idVendor}=="<lidar-vid>", ATTRS{idProduct}=="<lidar-pid>", SYMLINK+="lidar"
# Arduino Nano
SUBSYSTEM=="tty", ATTRS{idVendor}=="<arduino-vid>", ATTRS{idProduct}=="<arduino-pid>", SYMLINK+="arduino"
```

Reload with `sudo udevadm control --reload && sudo udevadm trigger`. (If both adapters share
a VID/PID, key the rule on `ATTRS{serial}` instead.) Either port can also be overridden on
the command line with `--lidar-port` / `--arduino-port`.

## 4. Run a challenge

From `src/rpi/` with the venv active:

```bash
python main_open.py                 # open challenge
python main_obstacle.py             # obstacle challenge
python main_obstacle.py --no-camera # obstacle main, LiDAR-only (bench / open)
```

By default the robot **waits for the start button** (press once to start, again to stop).
Useful flags (both mains share most of them):

| Flag | Effect |
|---|---|
| `--no-button` | auto-start ~2 s after launch (no button) |
| `--visu` | start the [visualizers](../../src/rpi/visu/README.md) (LiDAR 8082, planner 8084, colour 8085) |
| `--no-browser` | with `--visu`, don't auto-open a browser |
| `--no-record` | disable [recording](../../src/rpi/recording/README.md) |
| `--state-pause [SEC]` | debug: hold stopped for SEC s (default 2) at every state transition |
| `--lidar-port` / `--arduino-port` / `--camera-port` | override device paths |

`main_obstacle.py` adds parking options: `--parking-start` (start parked in the slot),
`--park-mode {none,perpendicular,...}`, `--park-exit-side {auto,left,right}`. See the
[processors chapter](../../src/rpi/processors/README.md#parking).

## 5. Remote access with Tailscale

We SSH into the Pi over a **Tailscale** private network, so the robot is reachable by a
stable hostname from anywhere, without port-forwarding or being on the same LAN.

One-time, on the Pi:

```bash
curl -fsSL https://tailscale.com/install.sh | sh
sudo tailscale up            # authenticate in the browser link it prints
```

Do the same on your laptop and log into the **same** Tailscale account. Then:

```bash
ssh <pi-user>@<robot-host>   # <robot-host> = the Pi's Tailscale name, e.g. from `tailscale status`
```

> Fill in `<pi-user>` (the Pi login) and `<robot-host>` (the Tailscale machine name — see
> `tailscale status`, or use the `100.x.y.z` Tailscale IP). The
> [visualizers](../../src/rpi/visu/README.md) are then reachable in a browser at
> `http://<robot-host>:8082` / `:8084` / `:8085` while a run with `--visu` is live.

For an untethered run: SSH in, start the main with `--no-button` (or press the physical
button), and watch the visualizers in the browser.

## 6. Record & replay a run

Every run writes `recordings/run_<timestamp>.h5` unless `--no-record` is given. To inspect one
(from `src/rpi/`):

```bash
python -m recording summary recordings/run_<ts>.h5    # streams, rates, sizes, drops
python -m recording scans   recordings/run_<ts>.h5    # per-scan LiDAR dropout
python -m recording dump     recordings/run_<ts>.h5 planner_debug --count 40
```

Copy a file off the robot with `scp <pi-user>@<robot-host>:~/…/recordings/run_<ts>.h5 .`.
The recorder and the replay-oriented `Recording` reader are documented in the
[recording chapter](../../src/rpi/recording/README.md); the planner's `on_debug` stream holds
everything the [planner visualizer](../../src/rpi/visu/README.md) draws, so a run can be
reconstructed after the fact.

## 7. Calibration

Before a competition, (re)run the relevant [calibration scripts](../../calibration/README.md)
— **always** the obstacle colours at the venue, and the camera intrinsics after any change to
the camera mount. Each script's output and where it is pasted is in that chapter.

## Typical bring-up checklist

1. `make flash` the firmware; confirm the `STATE` stream arrives (e.g. `python -m recording`
   on a short run, or the LiDAR/planner visualizers showing live data).
2. Create the `/dev/lidar` and `/dev/arduino` symlinks (step 3).
3. `pip install -r requirements.txt` in `src/rpi/.venv`.
4. `python main_obstacle.py --no-button --visu --no-camera` on the bench; watch 8082/8084.
5. Calibrate camera + colours; run the full obstacle main on the track.

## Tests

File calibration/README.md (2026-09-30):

# Calibration

Scripts that measure the camera constants the software depends on. Run each **once on the
assembled robot** — and re-run the colour calibration at every venue, because lighting
changes everything. Each output is pasted into the robot code as noted. This chapter is part
of the [developer & setup guide](../docs/software/setup-guide.md).

Calibration has its own lightweight environment (`calibration/requirements.txt`: `numpy`,
`opencv-python`) — set it up the same way as the
[Pi environment](../docs/software/setup-guide.md#2-raspberry-pi-python-environment), inside
`calibration/`.

| What | Script | Output goes to |
|---|---|---|
| Camera intrinsics | `camera/camera-intrinsics.py` (+ `camera/capture.py`) | `_CAMERA_INTRINSICS` in `main_obstacle.py` |
| Camera extrinsics | *manual measurement* | `_CAMERA_EXTRINSICS` in `main_obstacle.py` |
| Obstacle colours | `camera/obstacle-colors.py` | `_RED_COLOR` / `_GREEN_COLOR` / `_PARKING_COLOR` in `main_obstacle.py` |

## Running the GUI tools over SSH (XLaunch / VcXsrv)

The camera scripts open OpenCV windows — `capture.py` shows a live preview, and
`obstacle-colors.py` lets you draw selection boxes. When you run them **on the Pi over SSH**
from a Windows laptop, those windows have to be forwarded to an X server on the laptop. We use
**VcXsrv**, launched through **XLaunch**:

1. Install **VcXsrv** on the Windows machine and start **XLaunch**:
   - *Multiple windows*, **Display number `0`**
   - *Start no client*
   - tick **Disable access control** (so the Pi is allowed to connect)
2. SSH in with X11 forwarding and run the tool:
   ```bash
   ssh -Y <pi-user>@<robot-host>          # -Y = trusted X11 forwarding
   cd <repo>/calibration
   python camera/capture.py <out_dir>     # the preview window opens on your laptop
   ```
3. If no window appears, point the display at the laptop explicitly (VcXsrv listens on
   display 0) and re-run:
   ```bash
   export DISPLAY=<windows-host>:0.0      # <windows-host> = the laptop's Tailscale name / IP
   ```

Trusted forwarding needs `X11Forwarding yes` in the Pi's `sshd_config`. If you can't (or don't
want to) forward a display, every camera script also has a `--headless` mode that captures /
selects without a GUI — noted in each section below.

## Camera intrinsics

1. Print a **9 × 6** inner-corner checkerboard with **24.5 mm** squares.
2. Capture ≥ 15 shots from varied angles/distances:
   `python camera/capture.py <out_dir>` (`--headless` for no-GUI capture).
3. Solve: `python camera/camera-intrinsics.py <image_dir> <output_dir>`. It detects corners
   sub-pixel, discards images where detection fails, and runs `cv2.calibrateCamera`. Aim for
   a reprojection error < 0.5 px.
4. Paste `fx, fy, cx, cy, dist_coeffs` into `_CAMERA_INTRINSICS` in `main_obstacle.py`.

## Camera extrinsics (manual)

The camera's pose relative to the rear-axle (body) origin — measure with a ruler on the
assembled robot and update `_CAMERA_EXTRINSICS` in `main_obstacle.py`: `x` (lateral),
`y` (forward from rear axle), `z` (height), and `pitch / yaw / roll`. Verify it with the
[`ColorVisualizer`](../src/rpi/visu/README.md): a LiDAR-detected pillar must project onto the
pillar in the image. If it lands off the pillar, the extrinsics are wrong.

## Obstacle colours

Lighting varies between venues *and between corners*, so capture one photo per
segment/lighting condition where a pillar appears, and calibrate over all of them at once:

```bash
python camera/obstacle-colors.py <image1> <image2> ...
```

For each image, draw a box over the red pillar, then the green, then the magenta parking wall
(confirm an empty selection to skip a colour absent from that image). The script pools the
selected pixels per colour across all images into **one HSV range** per colour (red and the
magenta wall are split into two bands to handle the 0/180° hue wrap) and previews the merged
mask against each image. Paste the printed `ColorRange` blocks into `main_obstacle.py`. The
colour type is documented in the [control chapter](../src/rpi/control/README.md).

> The ROI picker is a GUI tool — run it over SSH with the XLaunch setup above, or pass
> `--headless` with an explicit `--red-roi` / `--green-roi` per image.

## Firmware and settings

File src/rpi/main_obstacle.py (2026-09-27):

import time
import argparse
import traceback
import webbrowser
from contextlib import ExitStack

import numpy as np

from gpiozero import Button

from components import Arduino, Camera, Lidar
from control import EgoInformation, TrackModel, ColorRange
from processors import (
    ArduinoProcessor,
    CameraProcessor,
    PrincipalAngleDetector,
    ObstacleChallengePlanner,
    CameraIntrinsics,
    CameraExtrinsics,
)
from recording import Recorder
from utils import mm, degree, Point

from visu.LidarVisualizer import LidarVisualizer
from visu.PathPlanningVisualizer import PathPlanningVisualizer
from visu.ColorVisualizer import ColorVisualizer

# Entry point for the obstacle-challenge planner.
# The planner drives from the raw LiDAR scan, the gyro heading, and the wheel
# odometry; the camera only supplies pillar colour via the stateless body-frame
# sampler and is a harmless no-op when no obstacle is queried. Pass --no-camera to
# skip it for the open challenge or bench runs without a camera.
#
# Parameters below mirror main_ftg.py exactly (wheelbase, LiDAR, camera).

_WHEELBASE:          mm     = 89.6251

_LIDAR_BAUDRATE:     int    = 115200
_LIDAR_OFFSET_ANGLE: degree = -90.0
_LIDAR_MOUNT_OFFSET: Point  = (0.0, 73.37)

_CAMERA_INTRINSICS = CameraIntrinsics(
    fx = 658.3516186667142,
    fy = 656.9839014361173,
    cx = 312.90122361261507,
    cy = 178.888473418321,
    dist_coeffs = np.array([
        -0.17756057290232585,
        -0.07620432808648203,
        0.0014254009734183857,
        0.0009633670165933481,
        -0.3014236479533136], dtype = np.float64
    )
)
_CAMERA_EXTRINSICS = CameraExtrinsics(
    x = 0.0, y = 134.696, z = 31.0747, pitch = 0.0, yaw = 0.0, roll = 0.0
)
# Obstacle + parking-wall colours. Each is a ColorRange = union of HSV bands (OpenCV
# H 0-180); a hue that wraps the 0/180 seam (red, or the magenta parking wall) uses two
# bands. Paste calibration output straight into these lists.
_RED_COLOR = ColorRange(bands = [
    (np.array([  0,  43,   4], dtype = np.uint8), np.array([ 10, 255, 255], dtype = np.uint8)),
    (np.array([170,  43,   4], dtype = np.uint8), np.array([180, 255, 255], dtype = np.uint8)),
])
_GREEN_COLOR = ColorRange(bands = [
    (np.array([ 33,  24,  28], dtype = np.uint8), np.array([ 97, 255, 231], dtype = np.uint8)),
])
_PARKING_COLOR = ColorRange(bands = [
    (np.array([  0, 150,  77], dtype = np.uint8), np.array([ 10, 217, 165], dtype = np.uint8)),
    (np.array([170, 150,  77], dtype = np.uint8), np.array([180, 217, 165], dtype = np.uint8)),
])


def guarded(handler, name):
    """Wrap an event handler so one exception can't silently kill its thread."""
    def wrapped(*args, **kwargs):
        try:
            handler(*args, **kwargs)
        except Exception:
            print(f"[{name}] handler error (continuing):")
            traceback.print_exc()
    return wrapped


def parse_args():
    parser = argparse.ArgumentParser(description = 'Obstacle-challenge planner')
    parser.add_argument('--lidar-port',   default = '/dev/lidar',   help = 'LiDAR serial port')
    parser.add_argument('--arduino-port', default = '/dev/arduino', help = 'Arduino serial port')
    parser.add_argument('--camera-port',  default = 0, type = int,  help = 'Camera device index')
    parser.add_argument('--button-pin',   default = 17, type = int, help = 'BCM GPIO pin for the start button')
    parser.add_argument('--no-button',    action = 'store_true', help = 'auto-start ~2 s after launch instead of waiting for the button')
    parser.add_argument('--no-camera',    action = 'store_true', help = 'skip the camera + colour reads (open challenge / no camera)')
    parser.add_argument('--parking-start', action = 'store_true', help = 'the run starts parked in the parking slot (play the leave maneuver first)')
    parser.add_argument('--park-mode', default = 'none',
                        choices = ('none', 'perpendicular', 'parallel_mirror', 'parallel_reverse'),
                        help = 'final parking maneuver at the end of the run (default: none = just stop)')
    parser.add_argument('--park-exit-side', default = 'auto', choices = ('auto', 'left', 'right'),
                        help = 'with --parking-start, which way the leave maneuver exits: '
                               'left=CCW, right=CW, auto=vote the LiDAR opening (default)')
    parser.add_argument('--no-record',    action = 'store_true', help = 'disable signal recording')
    parser.add_argument('--visu',         action = 'store_true', help = 'start the segment-planner + LiDAR visualizers')
    parser.add_argument('--no-browser',   action = 'store_true', help = 'with --visu, do not open the visualizers in a browser')
    parser.add_argument('--state-pause',  nargs = '?', const = 2.0, default = 0.0, type = float,
                        metavar = 'SEC',
                        help = 'debug: hold the robot stopped for SEC seconds at each state '
                               'transition (default 2 s when the flag is given, off otherwise)')
    return parser.parse_args()


def main():
    args = parse_args()

    ego_information = EgoInformation(wheelbase = _WHEELBASE)
    track           = TrackModel()

    lidar   = Lidar(port = args.lidar_port, baudrate = _LIDAR_BAUDRATE)
    arduino = Arduino(port = args.arduino_port)

    arduino_processor = ArduinoProcessor(ego_information)

    # Colour subsystem: the camera keeps the latest frame in the sampler; the planner
    # queries it on demand with a body-frame obstacle point. Skipped with --no-camera.
    camera:        Camera | None                = None
    color_sampler: CameraProcessor | None = None
    if not args.no_camera:
        camera        = Camera(port = args.camera_port)
        color_sampler = CameraProcessor(
            intrinsics = _CAMERA_INTRINSICS,
            extrinsics = _CAMERA_EXTRINSICS,
            red        = _RED_COLOR,
            green      = _GREEN_COLOR,
            parking    = _PARKING_COLOR,
        )
        camera.on_frame += guarded(color_sampler, 'camera')

    # PrincipalAngleDetector fits the track's principal angle into the shared TrackModel;
    # the planner reads it from there. It MUST be subscribed to on_scan before the planner
    # so it runs first on the LiDAR thread and the planner sees a fresh theta each scan.
    angle_detector = PrincipalAngleDetector(ego_information, track)

    planner = ObstacleChallengePlanner(
        ego_information,
        track,
        color_sampler      = color_sampler,
        lidar_mount_offset = _LIDAR_MOUNT_OFFSET,
        state_hold_s       = args.state_pause,
        start_in_parking   = args.parking_start,
        park_mode          = args.park_mode,
        park_exit_side     = args.park_exit_side,
    )

    lidar.on_scan += angle_detector
    lidar.on_scan += planner

    arduino.on_state  += arduino_processor
    planner.on_target += arduino.set_target
    planner.on_stop   += arduino.stop

    # Recorder taps go after the wiring above so ego_pose is sampled after
    # ArduinoProcessor has ingested the same state message.
    recorder = Recorder.create_default(enabled = not args.no_record)
    recorder.attach_scan(lidar.on_scan, ego = ego_information)
    recorder.attach_array(arduino.on_state, 'arduino_state',
                          fields = ('heading_rad', 'speed_mm_s', 'steering_rad', 'distance_mm'))
    recorder.attach_pose(arduino.on_state, ego_information)
    # recorder.attach_marker(collision_guard.on_collision, 'collision')
    recorder.attach_planner(planner)

    visualizers: list = []
    if args.visu:
        planner_visualizer = PathPlanningVisualizer()
        planner_visualizer.start()
        planner.on_debug += planner_visualizer.set_debug
        visualizers.append(planner_visualizer)

        lidar_visualizer = LidarVisualizer(offset_angle = _LIDAR_OFFSET_ANGLE)
        lidar_visualizer.start()
        lidar.on_scan += lidar_visualizer
        visualizers.append(lidar_visualizer)

        # Obstacle-colour view: only meaningful when the camera + sampler are wired.
        if color_sampler is not None:
            color_visualizer = ColorVisualizer(color_sampler)
            color_visualizer.start()
            camera.on_frame += color_visualizer
            visualizers.append(color_visualizer)

        if not args.no_browser:
            for vis in visualizers:
                webbrowser.open(f"http://localhost:{vis._DEFAULT_PORT}")

    start_button = None if args.no_button else Button(args.button_pin, pull_up = True)

    with ExitStack() as stack:
        stack.enter_context(recorder)
        stack.enter_context(lidar)
        stack.enter_context(arduino)
        if camera is not None:
            stack.enter_context(camera)

        if args.no_button:
            time.sleep(2)
        else:
            print("Ready. Press the start button to begin.")
            start_button.wait_for_press()
            print("Starting.")
            time.sleep(0.5)

        lidar.start()
        arduino.start()
        if camera is not None:
            camera.start()

        try:
            if args.no_button:
                print("Running. Ctrl-C to stop.")
                while True:
                    time.sleep(1)
            else:
                print("Running. Press the button again to stop.")
                start_button.wait_for_press()
                print("Stopping.")
        except KeyboardInterrupt:
            pass
        finally:
            arduino.stop()

    for vis in visualizers:
        vis.stop()


if __name__ == '__main__':
    main()

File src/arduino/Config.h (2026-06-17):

#ifndef CONFIG_H
#define CONFIG_H

#include <Arduino.h>
#include <math.h>

namespace config {

namespace pins{
    static constexpr int PIN_MOTOR_FWD = 5;
    static constexpr int PIN_MOTOR_REV = 6;
    static constexpr int PIN_SERVO     = 9;
    static constexpr int PIN_ENC_A     = 2;
    static constexpr int PIN_ENC_B     = 3;
} // namespace pins

namespace serial {
    static constexpr unsigned long SERIAL_BAUD = 115200UL;
} // namespace serial

namespace movement {
    static constexpr int   MOTOR_DIR         = -1;
    static constexpr float WHEEL_DIAMETER_MM = 43.2f;
    static constexpr float TICKS_PER_MM      = 14.0f;
    static constexpr float MAX_SPEED         = 255.0f;
    static constexpr float KICKSTART_DECAY   = 200.0f;
} // namespace movement

namespace steering {
    static constexpr int   SERVO_CENTER_US = 1050;
    static constexpr int   SERVO_LEFT_US   = 1400;
    static constexpr int   SERVO_RIGHT_US  = 500;
    static constexpr float MAX_STEER_RAD   = 0.4014f;
} // namespace steering

namespace encoder {
    static constexpr int SPEED_SAMPLE_MS = 50;
} // namespace encoder

namespace navigation {
    static constexpr float WHEELBASE_MM           = 89.6251f;
    static constexpr float HEADING_KP             = -2.5f;
    static constexpr float HEADING_KI             = -0.7f;
    static constexpr float HEADING_KD             = -0.155f;
    static constexpr float HEADING_I_CLAMP        = 0.3f;
    static constexpr float HEADING_D_FILTER       = 0.7f;
    static constexpr float HEADING_HOLD_RADIUS_MM = 100.0f;
    static constexpr float ARRIVAL_THRESHOLD_MM   = 10.0f;
    static constexpr float ACCEL_RADIUS_MM        = 200.0f;
    static constexpr float DECEL_RADIUS_MM        = 500.0f;
    static constexpr float MIN_SPEED              = 80.0f;
    static constexpr float REVERSE_STEER_SIGN     = -1.0f;
    static const     float MIN_TURNING_RADIUS_MM  = (WHEELBASE_MM / tanf(steering::MAX_STEER_RAD));
} // namespace navigation

namespace reporting {
    static constexpr int STATE_REPORT_INTERVAL_MS = 20;
} // namespace reporting

inline float wrapPi(float angle) {
    angle = fmodf(angle + M_PI, 2.0f * M_PI);
    if (angle < 0) {
        angle += 2.0f * M_PI;
    }
    return angle - M_PI;
}

} // namespace config

#endif // CONFIG_H

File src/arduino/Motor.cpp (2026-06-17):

#include "Motor.h"
#include "Config.h"

Motor motor;

void Motor::begin() {
    pinMode(config::pins::PIN_MOTOR_FWD, OUTPUT);
    pinMode(config::pins::PIN_MOTOR_REV, OUTPUT);
    setPwm(0.0f);
}

void Motor::setTarget(float speed) {
    if (stopped &&
        fabsf(speed) > 0.0f &&
        fabsf(speed) < config::navigation::MIN_SPEED) {
        current        = copysignf(config::navigation::MIN_SPEED, speed);
        kickstarting   = true;
        last_update_ms = millis();
    }
    target  = speed;
    stopped = false;
}

void Motor::stop() {
    target       = 0.0f;
    current      = 0.0f;
    stopped      = true;
    kickstarting = false;
    setPwm(0.0f);
}

void Motor::brake() {
    target       = 0.0f;
    current      = 0.0f;
    stopped      = true;
    kickstarting = false;
    analogWrite(config::pins::PIN_MOTOR_FWD, 255);
    analogWrite(config::pins::PIN_MOTOR_REV, 255);
}

void Motor::update() {
    if (stopped) {
        return;
    }

    if (kickstarting) {
        unsigned long now = millis();
        float         dt  = (now - last_update_ms) * 1e-3f;
        last_update_ms    = now;

        float step = config::movement::KICKSTART_DECAY * dt;
        if (fabsf(current) - fabsf(target) <= step) {
            current      = target;
            kickstarting = false;
        } else {
            current -= copysignf(step, current);
        }
    } else {
        current = target;
    }

    setPwm(
        constrain(
            current / config::movement::MAX_SPEED,
            -1.0f,
            1.0f
        ) * config::movement::MOTOR_DIR
    );
}

void Motor::setPwm(float normalized) {
    int pwm = static_cast<int>(fabsf(normalized) * 255.0f);
    pwm = constrain(pwm, 0, 255);

    if (normalized > 0.01f) {
        analogWrite(config::pins::PIN_MOTOR_FWD, pwm);
        analogWrite(config::pins::PIN_MOTOR_REV, 0);
    } else if (normalized < -0.01f) {
        analogWrite(config::pins::PIN_MOTOR_FWD, 0);
        analogWrite(config::pins::PIN_MOTOR_REV, pwm);
    } else {
        analogWrite(config::pins::PIN_MOTOR_FWD, 0);
        analogWrite(config::pins::PIN_MOTOR_REV, 0);
    }
}

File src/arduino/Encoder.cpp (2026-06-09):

#include "Encoder.h"
#include "Config.h"

Encoder encoder;

static void isrA() { encoder.isrA(); }
static void isrB() { encoder.isrB(); }

void Encoder::begin() {
    pinMode(config::pins::PIN_ENC_A, INPUT_PULLUP);
    pinMode(config::pins::PIN_ENC_B, INPUT_PULLUP);
    attachInterrupt(digitalPinToInterrupt(config::pins::PIN_ENC_A), ::isrA, CHANGE);
    attachInterrupt(digitalPinToInterrupt(config::pins::PIN_ENC_B), ::isrB, CHANGE);
    last_speed_time = millis();
}

void Encoder::isrA() {
    uint8_t a = digitalRead(config::pins::PIN_ENC_A);
    uint8_t b = digitalRead(config::pins::PIN_ENC_B);
    ticks += (a == b) ? 1 : -1;
}

void Encoder::isrB() {
    uint8_t a = digitalRead(config::pins::PIN_ENC_A);
    uint8_t b = digitalRead(config::pins::PIN_ENC_B);
    ticks += (a == b) ? -1 : 1;
}

void Encoder::update() {
    unsigned long now = millis();
    unsigned long dt  = now - last_speed_time;
    if (dt < config::encoder::SPEED_SAMPLE_MS) {
        return;
    }

    noInterrupts();
    int32_t t = ticks;
    interrupts();

    int32_t delta = t - last_speed_ticks;
    speed = ticksToMm(delta) / (dt * 0.001f);

    last_speed_ticks = t;
    last_speed_time  = now;
}

int32_t Encoder::getTicks() const {
    noInterrupts();
    int32_t t = ticks;
    interrupts();
    return t;
}

float Encoder::ticksToMm(int32_t ticks) const {
    return static_cast<float>(ticks) / config::movement::TICKS_PER_MM;
}

float Encoder::getSpeed() const {
    return speed;
}

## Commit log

2026-03-11 created lidar component class
2026-03-12 added type annotations to lidar, component and event classes
2026-03-13 fixed exception handling in component
    [Component.py, Lidar.py]
2026-03-14 created processor base class and lidar processor
2026-03-27 created camera calib helper scripts
2026-03-28 added headless mode to camera calib scripts
2026-04-04 created camera, camera processor, obstacles and camera visu
2026-04-10 changed lidar component's lidar package
2026-04-11 changed lidar event params type
2026-05-28 created arduino component and processor
2026-05-30 added device symlinks
2026-06-06 created arduino side protocol and movement
2026-06-09 added lidar exception handling
2026-06-14 added pid for steering, ramp for speed
2026-06-14 tuned odometry constants
2026-06-17 added reverse functionality to arduino side
    [Config.h, Motor.cpp, Navigator.cpp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]
2026-06-22 added 3d model files
    [DC_axle.3mf, DC_front_mount.3mf, DC_hub.3mf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]
2026-10-11 updated docs and created printable html
2026-10-14 camera calibration: broswer preview for capture, multi image color calib
